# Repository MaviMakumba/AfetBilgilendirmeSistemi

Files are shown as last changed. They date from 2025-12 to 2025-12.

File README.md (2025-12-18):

# 🏢 IoT Tabanlı Akıllı Bina Yönetimi ve Otonom Afet Güvenlik Sistemi






> **Sakarya Üniversitesi - Nesnelerin İnterneti (IoT) Dersi Projesi**

Bu proje, geleneksel bina güvenliğini (NFC/RFID) akıllı afet yönetimiyle birleştiren hibrit bir IoT sistemidir. Sistem, **iki ayrı NodeMCU modülü** üzerinden çalışarak; giriş-çıkışları kontrol eder, deprem/yangın anında otonom karar vererek kilitleri açar ve tüm verileri **Firebase** tabanlı Web Dashboard ve Mobil Uygulama üzerinden sunar.

---

## 🚀 Projenin Amacı ve Özgün Değeri
Mevcut akıllı ev sistemleri genellikle sadece konfora odaklanır. Bu projenin temel farkı **hayat kurtarmaya** odaklanmasıdır.
* **Otonom Tahliye (M2M):** Deprem algılandığında Sensör Modülü, Kapı Modülü ile **MQTT** üzerinden haberleşerek kilitli kapıları otomatik açar.
* **Gelişmiş Deprem Algılama:** Basit titreşim sensörü yerine, sismolojide kullanılan **STA/LTA (Short Term Average / Long Term Average)** algoritması ile MPU6050 verileri işlenerek hatalı alarmlar önlenir.

---

## 🛠 Donanım Mimarisi
Sistem iki ana düğümden oluşur:

### 1. Kapı ve Erişim Kontrol Ünitesi (NodeMCU-1)
* **Görev:** Personel takibi ve kapı kilidi kontrolü.
* **Bileşenler:**
    * NodeMCU V3 (ESP8266)
    * RC522 NFC/RFID Okuyucu
    * SG90 Servo Motor (Kilit Mekanizması)
    * Buzzer & LED (Durum Bildirimi)

### 2. Çevresel İzleme ve Afet İstasyonu (NodeMCU-2)
* **Görev:** Binayı sürekli dinleyen "Duyu Organı".
* **Bileşenler:**
    * NodeMCU V3 (ESP8266)
    * **MPU6050:** 6 Eksenli İvme ve Jiroskop (Deprem Tespiti)
    * **MQ-2:** Yanıcı Gaz ve Duman Sensörü
    * **LM35:** Analog Sıcaklık Sensörü
    * Alarm Sistemi (Buzzer & RGB LED)
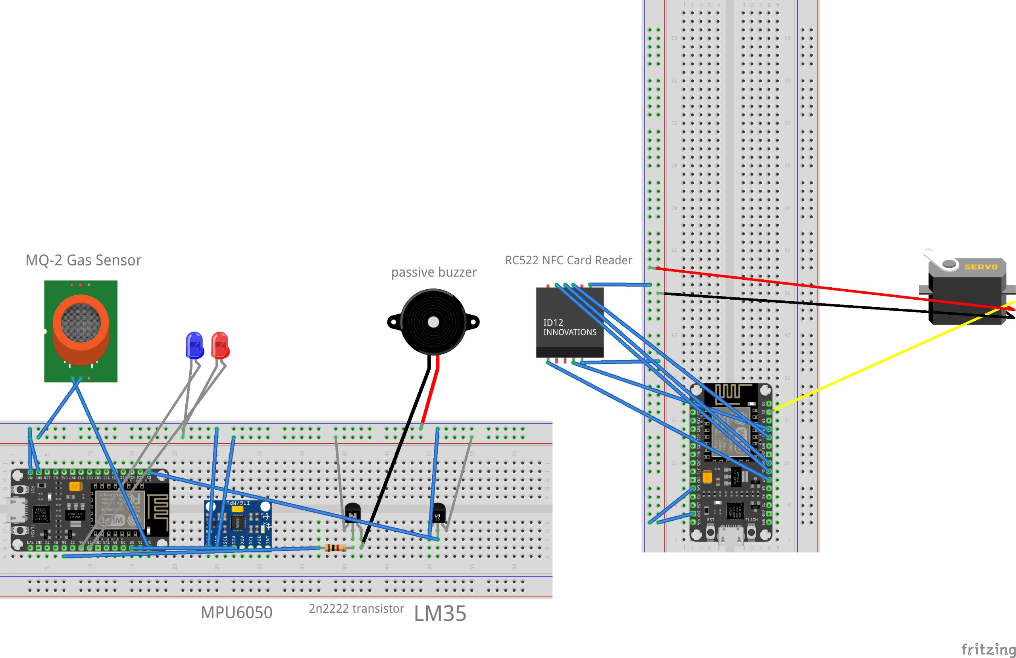
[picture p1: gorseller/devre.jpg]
Devre Resmi
    

---

## 💻 Yazılım ve Teknoloji Yığını

| Alan | Teknoloji / Platform | Kullanım Amacı |
| :--- | :--- | :--- |
| **Gömülü Yazılım** | Arduino IDE (C++) | ESP8266 kodlaması ve STA/LTA algoritması. |
| **Veritabanı** | Firebase Realtime DB | Kullanıcı verileri, loglar ve anlık durum senkronizasyonu. |
| **Haberleşme** | Adafruit IO (MQTT) | İki NodeMCU arasındaki M2M (Makineden Makineye) iletişim. |
| **Web Panel** | .NET MVC (C#) | Yönetici paneli, grafiksel raporlama ve geçmiş veri analizi. |
| **Mobil Panel** | Blynk IoT | Cepten anlık izleme ve "Push Notification" bildirimleri. |
| **Kart Yönetimi** | MIT App Inventor | NFC kartlara kişi tanımlamak için geliştirilen mobil araç. |

---

## 📊 Sistem Görselleri ve Arayüzler

### Web Dashboard (.NET MVC)
Sistemin genel durumunun, anlık gaz/sıcaklık verilerinin ve giriş-çıkış loglarının takip edildiği yönetim paneli.
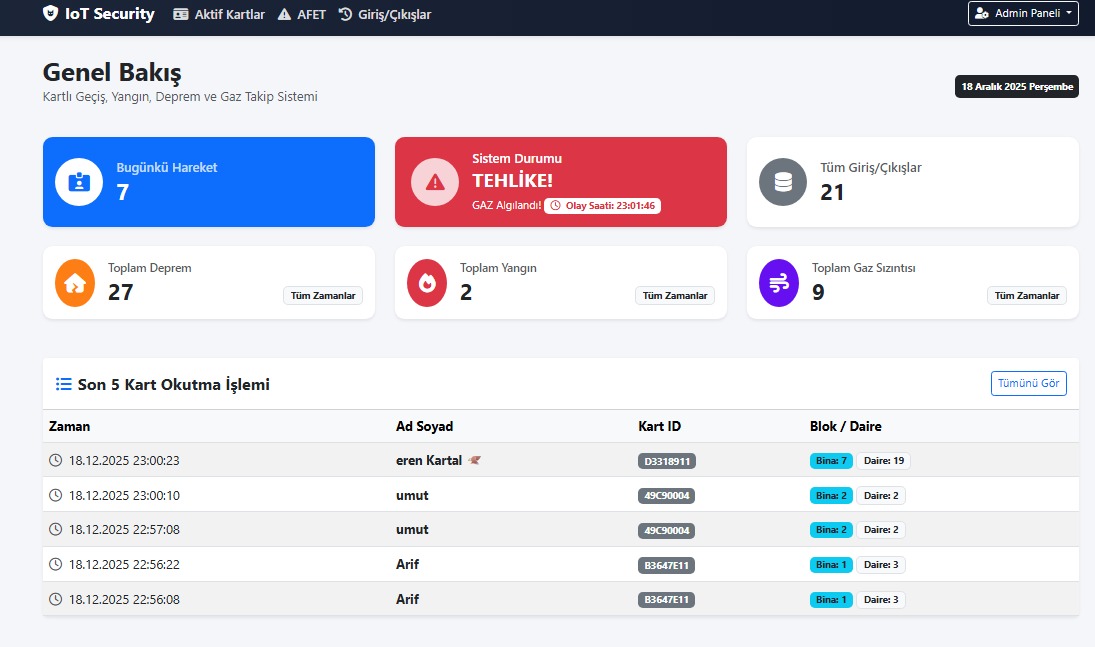
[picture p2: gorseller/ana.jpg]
AnaMenu

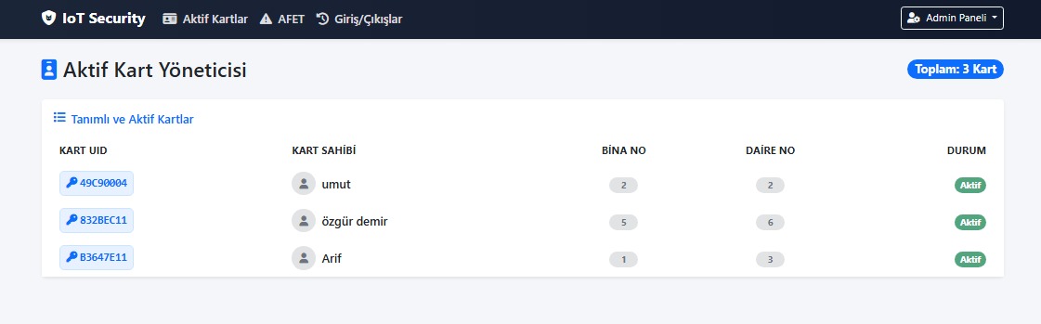
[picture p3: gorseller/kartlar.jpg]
Kartlar

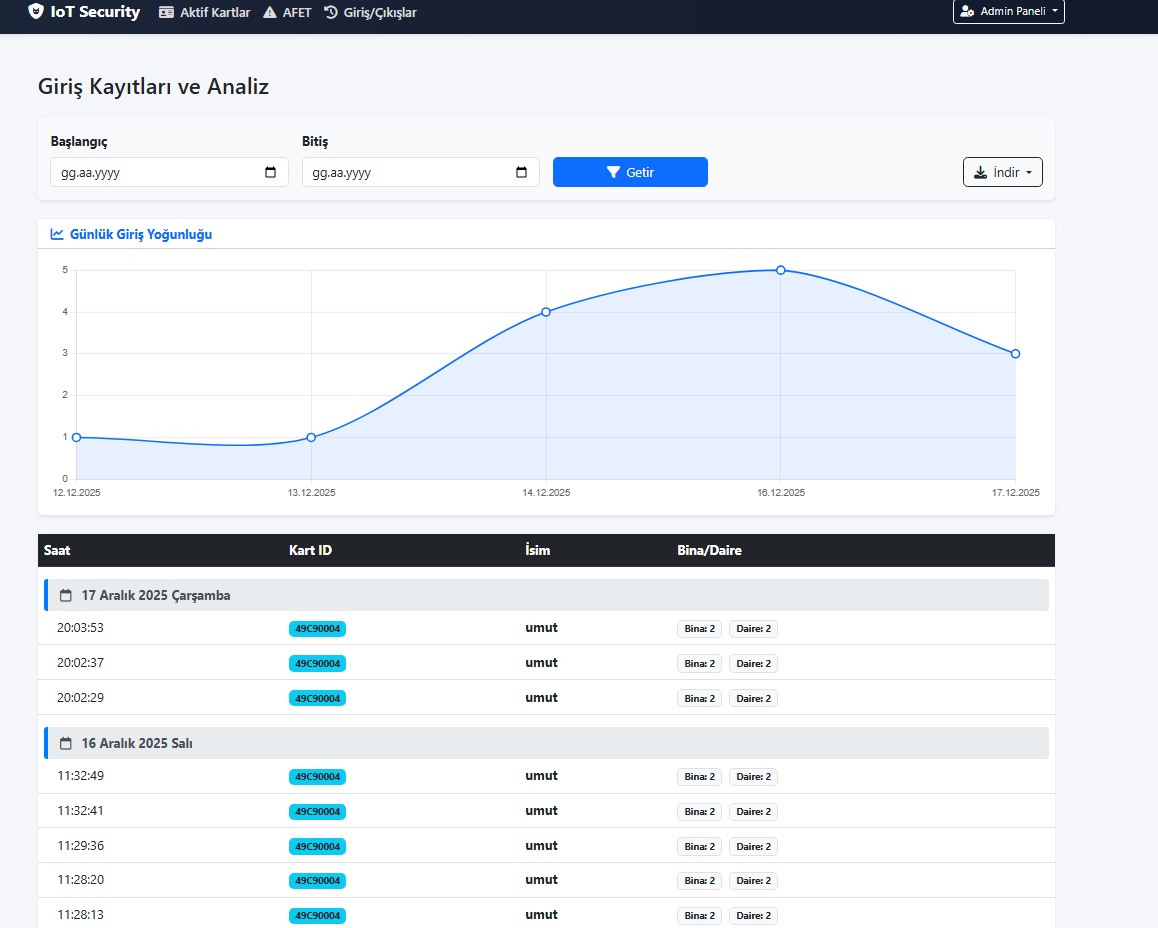
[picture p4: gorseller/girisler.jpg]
Girisler

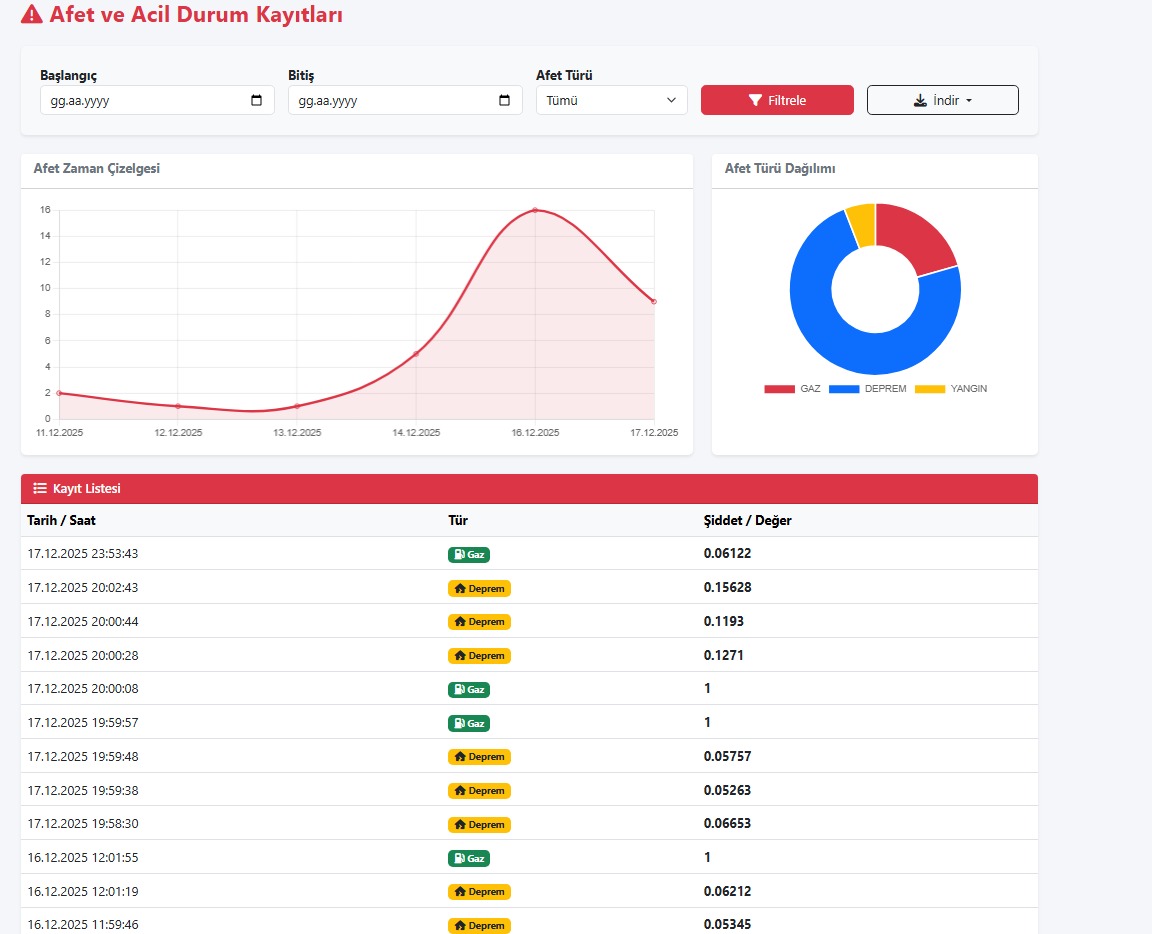
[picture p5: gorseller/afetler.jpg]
Afetler


### Mobil Uygulamalar
* **Blynk:** Ev sahibinin alarm durumunu gördüğü ekran.
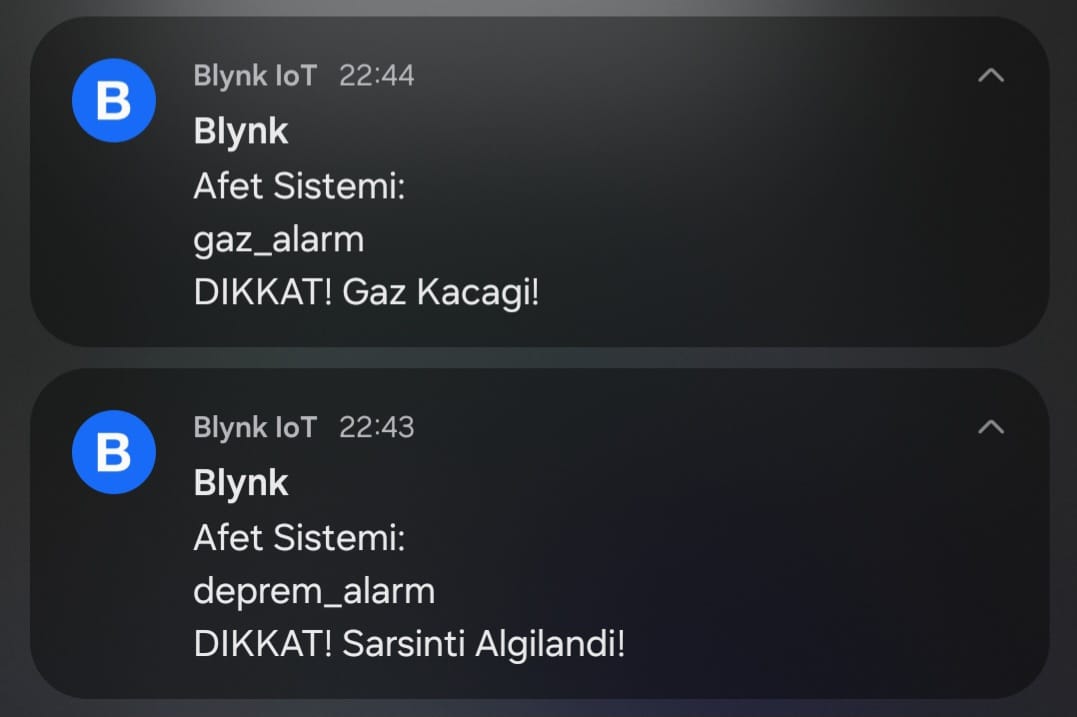
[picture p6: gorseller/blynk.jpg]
Blynk
 

* **Kart Yöneticisi:** Yöneticinin yeni kiracı/personel kartı tanımladığı arayüz.
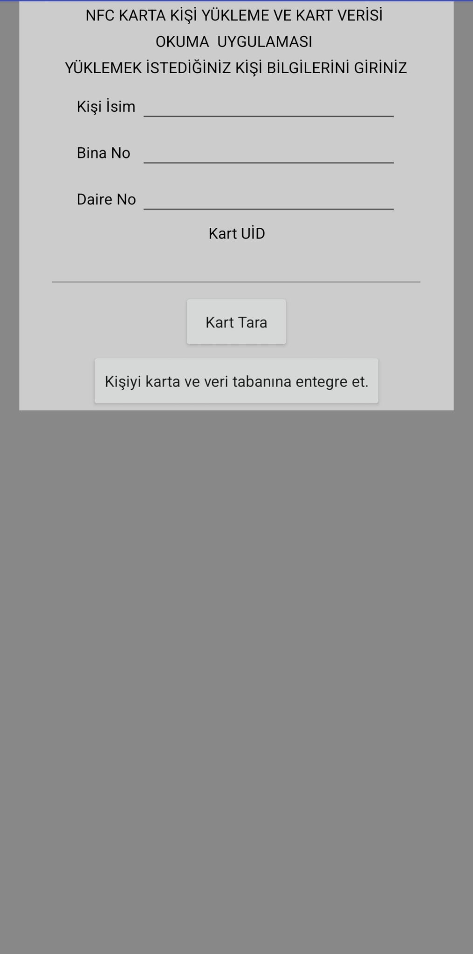
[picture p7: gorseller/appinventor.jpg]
AppInventor


---

## ⚙️ Kurulum ve Algoritma Detayları

### STA/LTA Deprem Algoritması
Sistem, sadece "sallantı var" demez; sarsıntının karakteristiğini analiz eder.
* **STA (Kısa Dönem):** Son 0.5 saniyedeki ivme ortalaması.
* **LTA (Uzun Dönem):** Son 30 saniyedeki zemin gürültüsü ortalaması.
* **Tetiklenme:** `Oran = STA / LTA`. Eğer Oran > 2.5 ise sistem **DEPREM** alarmı verir ve kapıları açar.

### Nasıl Çalıştırılır?
1.  `Arduino/` klasöründeki kodları NodeMCU kartlarına yükleyin.
2.  `WebPanel/` klasöründeki .NET projesini Visual Studio ile açıp Firebase bilgilerinizi girin.
3.  Blynk uygulamasından QR kodu taratarak mobil arayüzü klonlayın.

---

## 👥 Proje Ekibi
* **Eren Kartal** - B231210065
* **Umut Arda Vural** - B231210081
* **Özgür Demir** - B221210017

---
*Sakarya Üniversitesi, Bilgisayar ve Bilişim Bilimleri Fakültesi*

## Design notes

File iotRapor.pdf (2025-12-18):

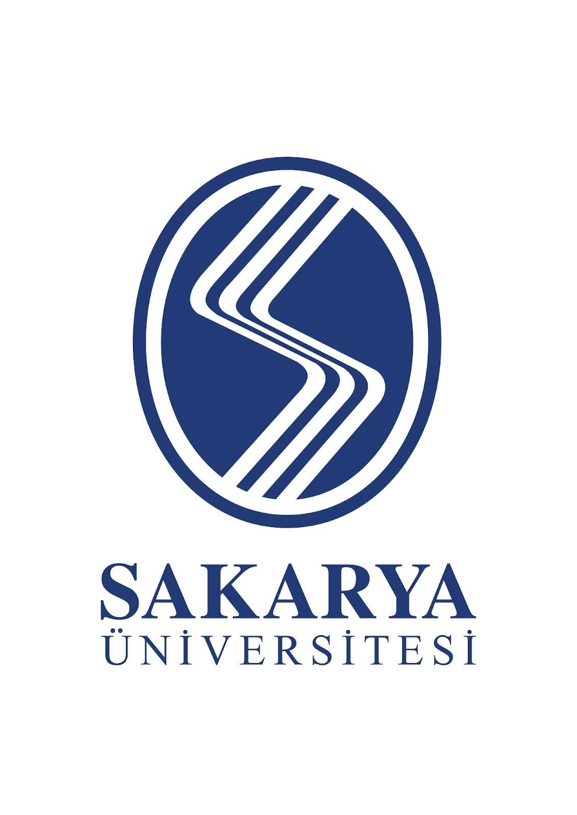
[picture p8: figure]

1) Proje Raporu
Proje Adı: IoT Tabanlı Akıllı Bina Yönetimi ve Otonom Afet Güvenlik Sistemi Ders: Nesnelerin İnterneti (IoT)
Platformlar: NodeMCU (ESP8266), Firebase Realtime Database, Adafruit MQTT, Blynk IoT Platformu
Hazırlayanlar:
Eren Kartal B231210065
Umut Arda Vural B231210081 Özgür Demir B221210017
Tarih: 19.12.2025
Özet
Bu proje, binalarda giriş-çıkış güvenliğini sağlayan ve aynı zamanda doğal afetlere (deprem, yangın) veya gaz sızıntılarına karşı otonom tepki verebilen entegre bir bina yönetim sistemidir. Sistem iki ana haberleşme düğümünden oluşur. Birinci düğüm; NFC teknolojisi ile personel/bina sakini takibi yapar, girişleri zaman damgalı olarak buluta (Firebase) kaydeder ve yetkisiz girişleri engeller. İkinci düğüm ise binanın "duyu organı" gibi çalışarak sarsıntı (MPU6050), sıcaklık (LM35) ve gaz (MQ-2) seviyelerini sürekli analiz eder.
Projenin en özgün yanı, M2M (Makineden Makineye) iletişim protokolü kullanmasıdır. Deprem algılandığı anda sensör düğümü, MQTT protokolü üzerinden kapı düğümüne sinyal göndererek kilitli kapıların otomatik açılmasını sağlar. Bu sayede panik anında tahliye süreci hızlandırılır ve can güvenliği maksimize edilir. Amaç ve Hedefler
Amaç: Geleneksel bina güvenliğini (kartlı geçiş), akıllı afet yönetimiyle birleştirerek; hem günlük kullanımda konfor sağlayan hem de acil durumlarda otonom kararlar alabilen hibrit bir IoT sistemi geliştirmek.
Hedefler:

### 1. Bulut Tabanlı Loglama: Binaya kimin, ne zaman girdiğinin anlık olarak

Firebase veritabanına işlenmesi.

### 2. Yönetici Kolaylığı: Kod güncellemesine gerek kalmadan, "Master Kart"

kullanılarak yeni kullanıcıların sisteme fiziksel olarak eklenebilmesi.

### 3. Gelişmiş Deprem Algılama: Basit titreşim sensörleri yerine 6 eksenli

ivmeölçer (MPU6050) ve STA/LTA (Kısa Dönem/Uzun Dönem Ortalaması) algoritması kullanarak hatalı alarmları önleyen sismik algılama.

### 4. Acil Durum Senaryosu (M2M): Deprem veya yangın anında insan

müdahalesine gerek kalmadan kapı kilitlerinin (Servo) otomatik açılması.

### 5. Mobil İzleme: Bina yöneticisinin Blynk uygulaması üzerinden sıcaklık, gaz ve

sarsıntı durumunu canlı izleyebilmesi ve anlık "Push Notification" alabilmesi.
Sistem Gereksinimleri
Donanım Bileşenleri
- Mikrodenetleyici: 2 x NodeMCU V3 (ESP8266 Wi-Fi Modülü).
- Biri Kapı Kontrol Ünitesi, diğeri Sensör İstasyonu olarak.
- Kimlik Doğrulama: 1 x MFRC522 RFID/NFC Okuyucu Kit (13.56 MHz).
- Mekanik Kontrol: 1 x SG90 Servo Motor (Kapı kilidi simülasyonu için).
- Sensörler:
- 1 x MPU6050 (3 Eksen İvme ve 3 Eksen Jiroskop) - Deprem için.
- 1 x MQ-2 (Yanıcı Gaz ve Duman Sensörü).
- 1 x LM35 (Analog Sıcaklık Sensörü).
- Uyarıcılar: 1 x Pasif Buzzer, 2 x Led Modülü. Devre Tasarımı

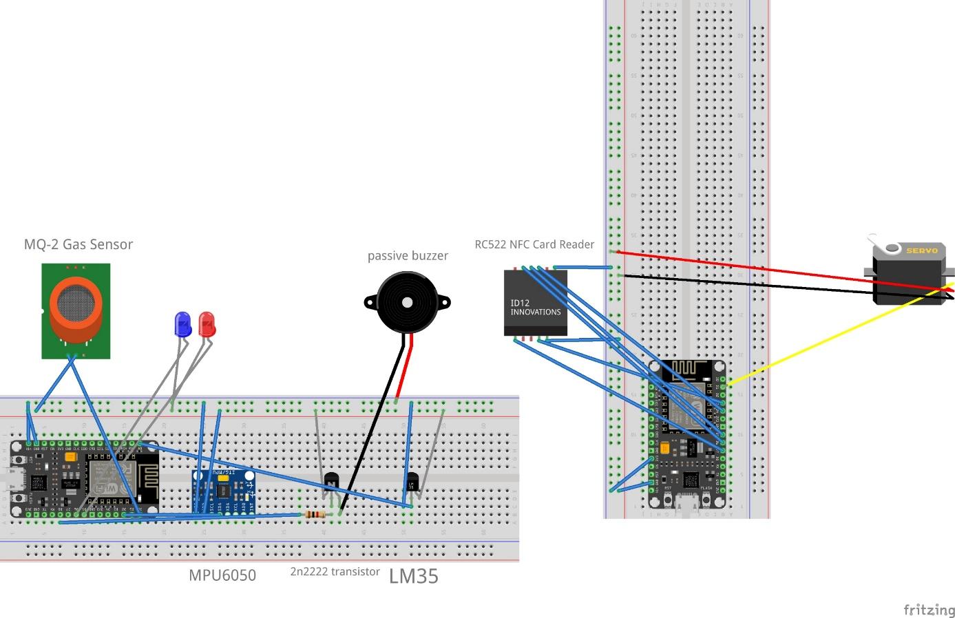
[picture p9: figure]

Yazılım ve Bulut Teknolojileri
- Geliştirme Ortamı: Arduino IDE (C++).
- Veritabanı: Google Firebase Realtime Database (JSON formatında veri saklama).
- Haberleşme Protokolü: Adafruit IO (MQTT Broker) – Cihazlar arası iletişim için.
- Kullanıcı Arayüzü: Blynk IoT (Mobil Dashboard).
- Zaman Sunucusu: NTP (Network Time Protocol) – Loglara doğru tarih/saat basmak için.
Mimari Tasarım
Sistem, birbirinden bağımsız çalışan ancak MQTT üzerinden haberleşen iki ana modülden oluşur:

### 1. Modül: Akıllı Kapı ve Erişim Kontrol Ünitesi

- Firebase ile sürekli senkronize çalışır.
- Okunan kartın ID'sini veritabanından sorgular.
- Yetkili ise servo motoru 90 derece açar, 5 saniye bekler ve kapatır.

- Kritik Görev: Arka planda sürekli MQTT kanalını dinler. Eğer "Acil Durum" mesajı gelirse kart sormadan kapıyı açar.

### 2. Modül: Çevresel İzleme ve Afet Tespit Ünitesi

- Sensör verilerini sürekli işler (Loop döngüsü içinde).
- Deprem için matematiksel STA/LTA algoritması koşturur.
- Tehlike (Gaz/Yangın/Deprem) tespit ettiğinde:
1. Sesli ve Işıklı (Kırmızı LED) alarm verir.
2. Blynk uygulamasına bildirim atar.
3. Firebase "Afet_Gecmisi" tablosuna olayı kaydeder.
4. MQTT üzerinden kapı modülüne "AÇ" komutu yollar. UML Tasarımları
(Bu bölümdeki diyagramları raporuna görsel olarak eklemelisin. Aşağıdaki metinler diyagramların mantığını anlatır.)
1) Use Case Diyagramı
- Aktörler: Bina Sakini, Yönetici, Sistem (Otonom).
- Senaryolar:
- Kartlı Giriş: Bina sakini kart okutur -> Sistem kapıyı açar.
- Kart Ekleme: Yönetici Master kartı okutur -> Sistem "Kayıt Modu"na geçer.
- Afet Yönetimi: Sistem depremi algılar -> Kapıları açar -> Yöneticinin telefonuna bildirim gönderir.

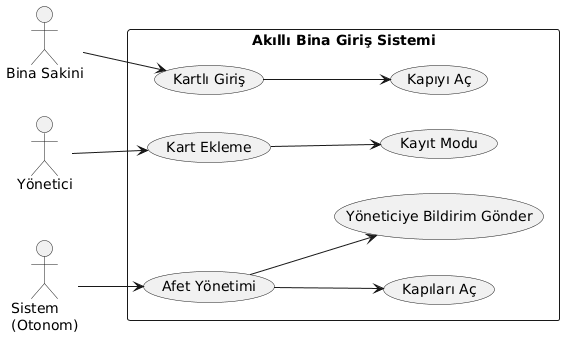
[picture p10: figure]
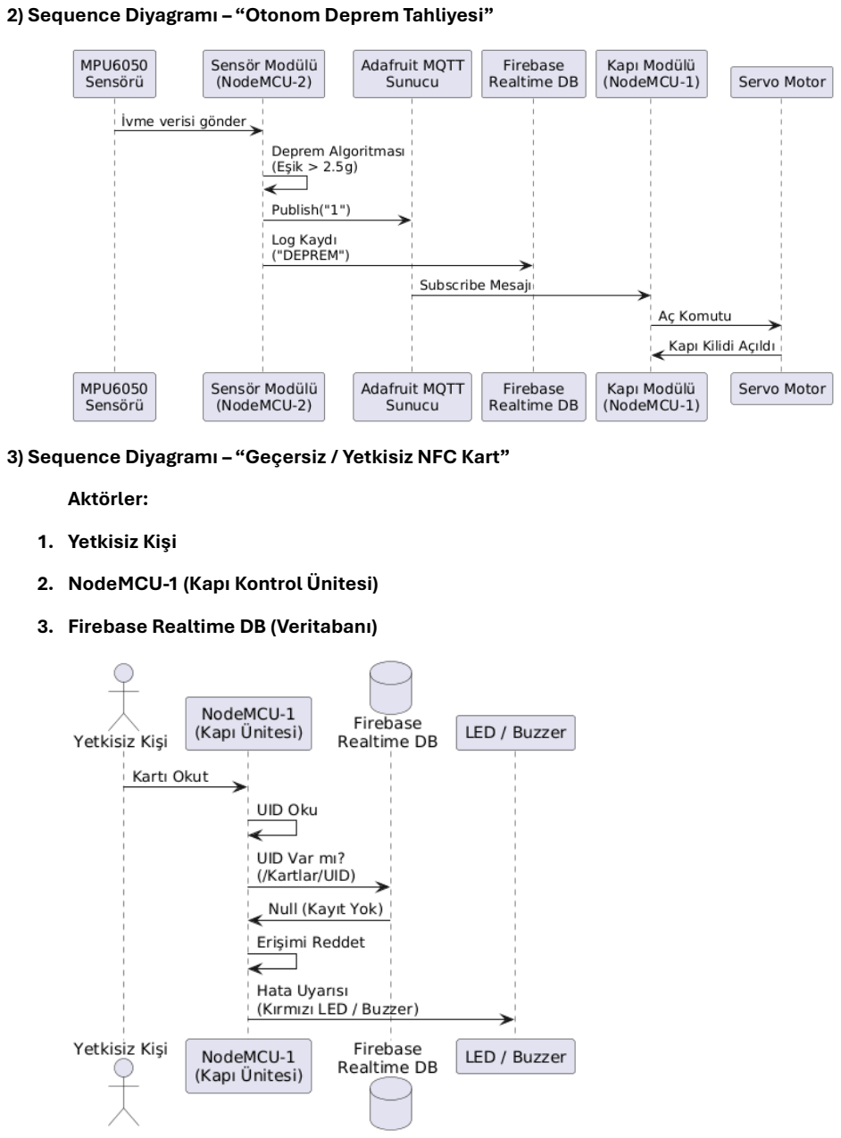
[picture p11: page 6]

2) Sequence Diyagramı – “Otonom Deprem Tahliyesi”
3) Sequence Diyagramı – “Geçersiz / Yetkisiz NFC Kart” Aktörler:

### 1. Yetkisiz Kişi

### 2. NodeMCU-1 (Kapı Kontrol Ünitesi)

### 3. Firebase Realtime DB (Veritabanı)

4) Component (Bileşen) Diyagramı
A) NodeMCU-1 (Kapı ve Giriş Ünitesi) Bu kutunun içine şu modülleri yaz:
- NFC Reader Service: Kart okuma işlemi.
- Firebase Auth Client: Veritabanı yetki sorgulama.
- Lock Controller: Servo motoru yöneten kısım.
- MQTT Subscriber: Deprem sinyalini dinleyen modül.
B) NodeMCU-2 (Sensör ve Afet Ünitesi) Bu kutunun içine şu modülleri yaz:
- Sensor Manager: MPU6050, MQ-2 ve LM35 verilerini okuyan kısım.
- Earthquake Algo (STA/LTA): Deprem hesaplaması yapan algoritma.
- Alarm Controller: Buzzer ve RGB LED yönetimi.
- Blynk Client: Mobil uygulamaya veri gönderme.
- MQTT Publisher: Deprem anında kapıya "Aç" sinyali gönderen modül.
- Firebase Logger: Afet verilerini kaydeden kısım.
C) Cloud Services (Bulut Katmanı) Bu kutunun içine şu servisleri yaz:
- Firebase Realtime DB: Kullanıcı listesi ve Loglar.
- Adafruit IO (MQTT Broker): İki cihazın konuşma hattı.
- Blynk Server: Mobil uygulama sunucusu.

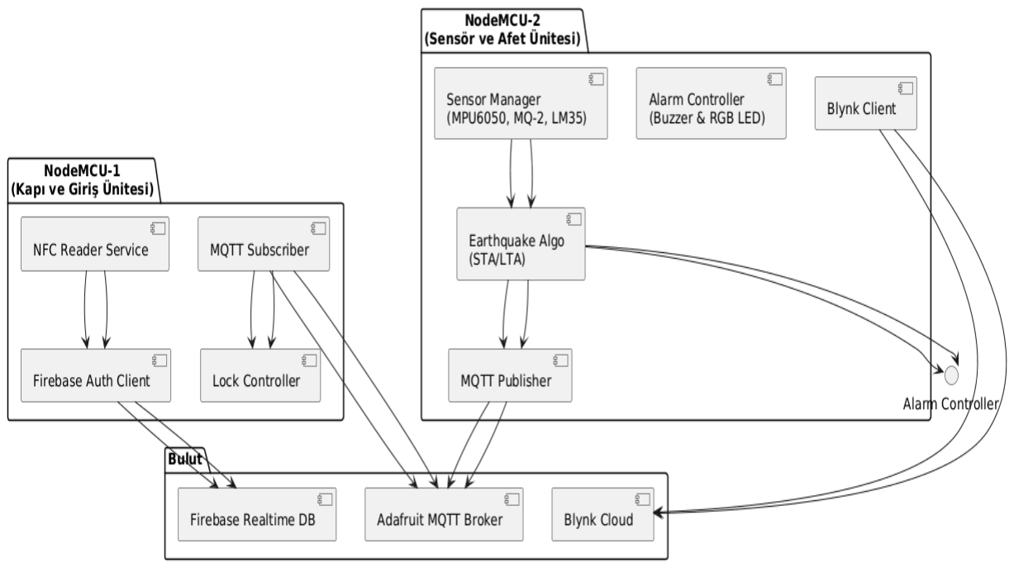
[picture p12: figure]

Elektronik Devre Tasarımı (Pin Bağlantıları)
A) Kapı Kontrol Ünitesi (NodeMCU-1)
- MFRC522 (NFC):
- SDA (SS) -> D4
- SCK -> D5
- MOSI -> D7
- MISO -> D6
- RST -> D3
- Servo Motor: Sinyal Pini -> D1 (PWM).
B) Sensör ve Afet Ünitesi (NodeMCU-2)
- MPU6050 (Deprem): SDA -> D2, SCL -> D1 (I2C Hattı).
- MQ-2 (Gaz): Analog/Dijital Çıkış -> D0.
- LM35 (Sıcaklık): Sinyal -> A0.
- Buzzer: Pozitif -> D8.
- RGB LED: Kırmızı -> D5, Yeşil -> D6, Mavi -> D7. Gerçekleme Süreci ve Yazılım Mantığı
Projenin yazılımında üç kritik algoritma kullanılmıştır:

### 1. Dinamik Kart Yönetimi: Kod içinde MASTER_KART_ID olarak belirlenen kart

okutulduğunda, cihaz bir durum makinesi (State Machine) gibi davranarak "Kayıt Modu"na geçer. Bu modda okutulan herhangi bir yabancı kart, otomatik olarak Firebase JSON ağacına yeni kullanıcı olarak eklenir.

### 2. STA/LTA Deprem Algoritması: Deprem tespiti için sadece "titreşim var mı?"

kontrolü yapılmamıştır. Sismolojide kullanılan, kısa süreli ortalamanın (STA) uzun süreli ortalamaya (LTA) oranlanması yöntemi kullanılmıştır.
- Formül: Oran = STA / LTA
- Eğer oran 2.5 değerini aşarsa ve ivme belirli bir büyüklükteyse, sistem bunu "anlık çarpma" değil "sismik hareket" olarak yorumlar.

### 3. JSON Veri Paketleme: Firebase'e veri gönderilirken ham string yerine

FirebaseJson kütüphanesi kullanılmıştır. Bu sayede veriler { "isim": "Ahmet", "tarih": "18.12.2025", "kart_id": "XXYY" } formatında yapısal olarak saklanır.

Test Planı ve Sonuçlar
- Test 1: Normal Giriş: Tanımlı NFC kart okutuldu.
- Beklenen: Servo motor 90° döndü, Firebase "Giris_Kayitlari"na log düştü.
- Sonuç: Başarılı. Yeşil LED yandı.
- Test 2: Yetkisiz Giriş: Tanımsız kart okutuldu.
- Beklenen: Kapı açılmadı, Servo tepki vermedi.
- Sonuç: Başarılı. Seri port ekranında "Erişim Reddedildi" uyarısı görüldü.
- Test 3: Deprem Simülasyonu: Sensör modülü el ile sertçe sarsıldı.
- Beklenen: Buzzer çaldı, Blynk bildirimi geldi, Kapı modülündeki servo otomatik açıldı.
- Sonuç: MQTT gecikmesi <1 saniye olarak ölçüldü. Kapı başarıyla açıldı.
- Test 4: Gaz Kaçağı: Sensöre çakmak gazı yaklaştırıldı.
- Beklenen: Blynk uygulamasında "Gaz Kaçağı" uyarısı görüldü.
- Sonuç: Başarılı. Kırmızı alarm LED'i yandı.
Maliyet Analizi
Bileşen Adı | Adet | Birim Fiyat (Tahmini) | Toplam
NodeMCU V3 (ESP8266) | 2 | 150 TL | 300 TL
MFRC522 NFC Kiti | 1 | 90 TL | 90 TL
MPU6050 İvme Sensörü | 1 | 150 TL | 150 TL
MQ-2 Gaz Sensörü | 1 | 70 TL | 70 TL
SG90 Servo Motor | 1 | 75 TL | 75 TL
LM35 Sıcaklık Sensörü | 1 | 20 TL | 20 TL
Jumper & Breadboard | 1 | 100 TL | 100 TL
GENEL TOPLAM | | | 805 TL

2) İş Fikri ve Business Model Canvas
İş Fikri: " IoT Tabanlı Akıllı Bina Yönetimi ve Otonom Afet Güvenlik Sistemi" Problem: Mevcut akıllı bina sistemleri konfora odaklıdır ancak afet anında işgörmez kilitlere dönüşmektedir. Deprem anında kapıların sıkışması veya kilitli kalması, tahliyeyi imkansız hale getirebilir. Ayrıca gaz kaçakları, deprem sonrası ikincil felaketlere yol açmaktadır.
Çözüm: Giriş güvenliğini sağlarken aynı zamanda binayı sürekli dinleyen, deprem anında kapıları otomatik açarak "kaçış yolu yaratan" entegre bir sistem. Business Model Canvas Özeti:

### 1. Değer Önerisi: "Sadece kapınızı açmaz, hayatınızı kurtarır." Deprem anında

otonom tahliye garantisi.

### 2. Müşteri Segmentleri: Deprem riski yüksek bölgelerdeki (İstanbul vb.) site

yönetimleri, kentsel dönüşüm projeleri, akıllı ev sahipleri.

### 3. Gelir Akışları: Donanım satışı + Bulut loglama hizmeti için yıllık abonelik

(SaaS).

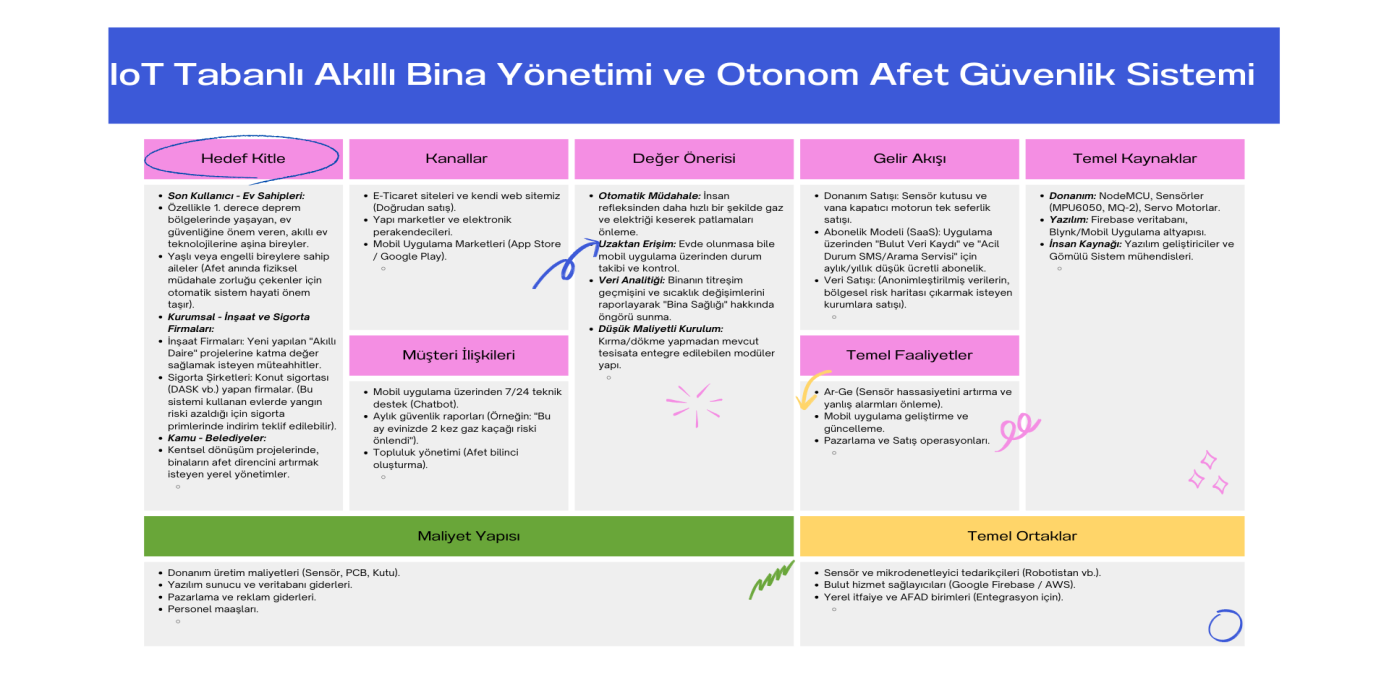
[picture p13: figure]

3) Büyük Veri (Big Data) Potansiyeli
Eğer bu sistem binlerce binada (örneğin tüm İstanbul'da) aktif olsaydı, elde edilecek veri muazzam bir değer taşırdı:

### 1. Kitle Kaynaklı Sismograf Ağı (Crowdsourced Seismology):

Her binadaki MPU6050 sensörü, depremin yayıldığı saniyelerde bir veri noktası oluşturur. Binlerce cihazdan gelen bu veriler;

- Depremin merkez üssünü saniyeler içinde doğrulayabilir.
- Hangi mahallelerin daha şiddetli sarsıldığını gösteren "Anlık Hasar Tahmin Haritası" çıkarabilir.

### 2. Gaz ve Yangın Risk Haritası:

Binalardan gelen MQ-2 verileri analiz edilerek, şehirdeki gaz kaçağı riskinin yüksek olduğu, altyapının eski olduğu bölgeler tespit edilebilir.
Gerekli Altyapı:
- Bu kadar büyük veriyi işlemek için Firebase yerine Apache Kafka (Stream Processing) ve MongoDB (Big Data Storage) gibi teknolojilere geçiş yapılmalıdır.
- Anlık analiz için yapay zeka destekli Anomaly Detection (Anomali Tespiti) algoritmaları kullanılmalıdır.
Uygulama Resimleri

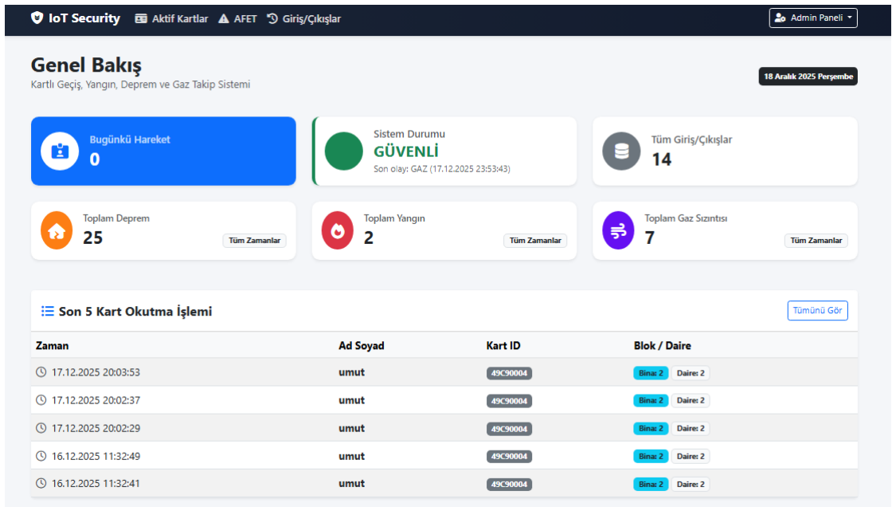
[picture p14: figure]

Şekil 1: .NET MVC mimarisi ile geliştirilen ve verileri Firebase üzerinden anlık olarak çeken "IoT Security" projesinin Genel Bakış (Dashboard) ekranı. Bu panelde sistemin güvenlik durumu, toplam afet istatistikleri ve son kartlı geçiş hareketleri özetlenmektedir.

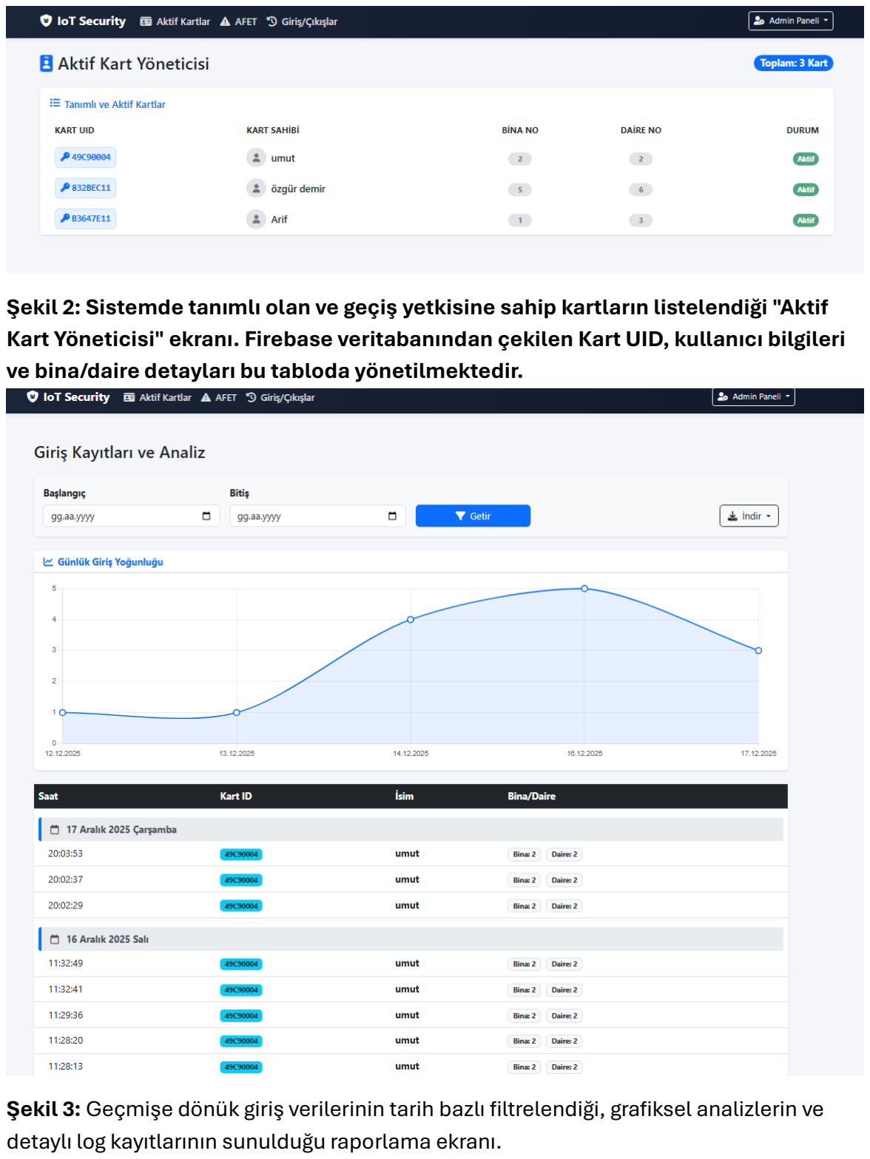
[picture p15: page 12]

Şekil 2: Sistemde tanımlı olan ve geçiş yetkisine sahip kartların listelendiği "Aktif Kart Yöneticisi" ekranı. Firebase veritabanından çekilen Kart UID, kullanıcı bilgileri ve bina/daire detayları bu tabloda yönetilmektedir.

Şekil 3: Geçmişe dönük giriş verilerinin tarih bazlı filtrelendiği, grafiksel analizlerin ve detaylı log kayıtlarının sunulduğu raporlama ekranı.

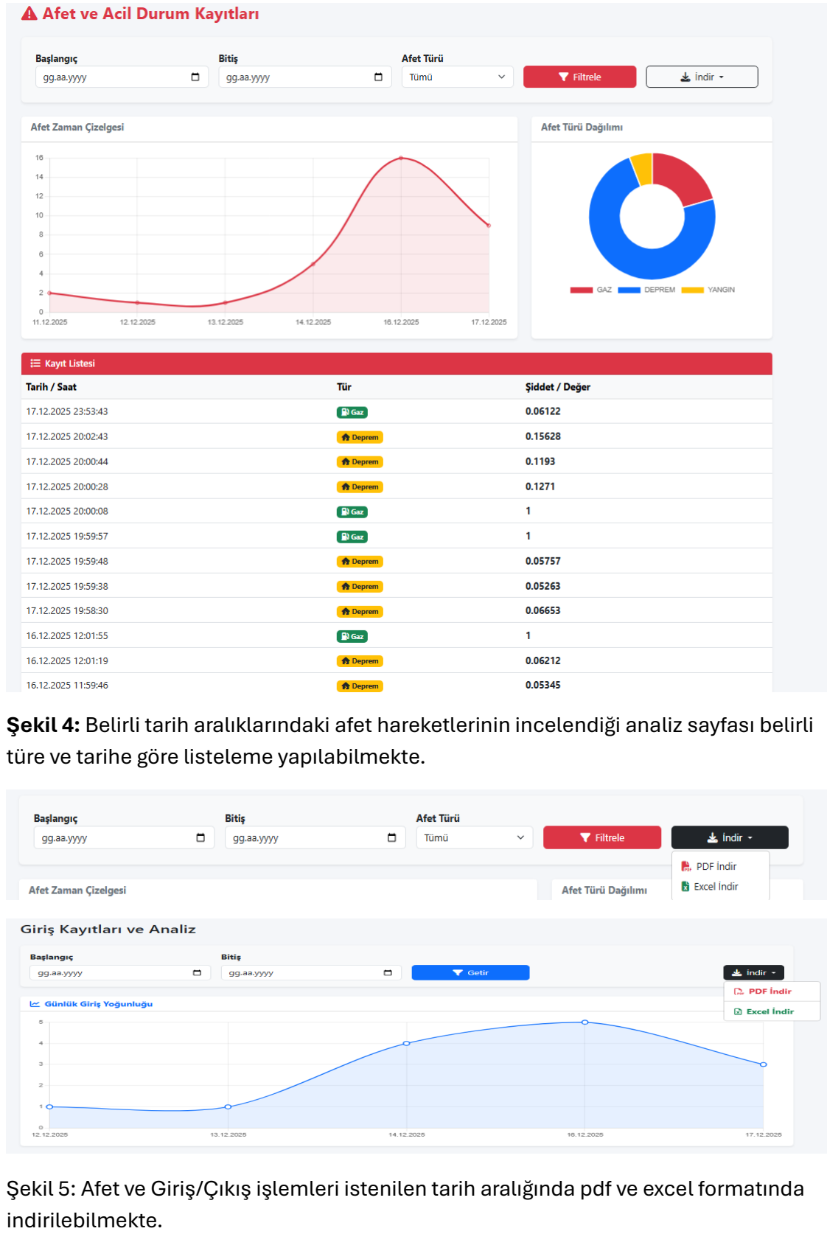
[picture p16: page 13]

Şekil 4: Belirli tarih aralıklarındaki afet hareketlerinin incelendiği analiz sayfası belirli türe ve tarihe göre listeleme yapılabilmekte.

Şekil 5: Afet ve Giriş/Çıkış işlemleri istenilen tarih aralığında pdf ve excel formatında indirilebilmekte.

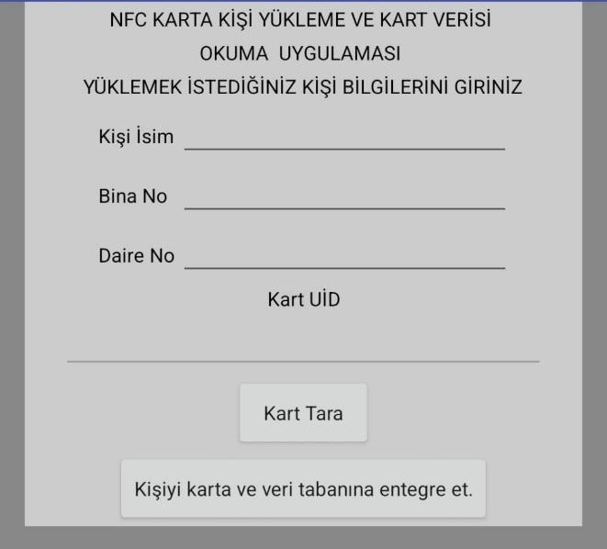
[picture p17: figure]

Şekil 6: Donanım tarafında "Admin Kart" protokolü ile kilidi açılan kartların tanımlandığı mobil arayüz. "Kart Tara" butonu ile sisteme son okutulan hedef kartın UID'si çekilir; girilen kullanıcı bilgileri hem Firebase veritabanına işlenir.( App Inventor)

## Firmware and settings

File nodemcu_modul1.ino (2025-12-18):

#define BLYNK_TEMPLATE_ID "TMPL6_E93vIuf"
#define BLYNK_TEMPLATE_NAME "Afet Sistemi"
#define BLYNK_AUTH_TOKEN "uVb_FSvif9LfXYwK0c1Onp_nOEmY2oFg"

#define BLYNK_PRINT Serial
#include <ESP8266WiFi.h>
#include <BlynkSimpleEsp8266.h>
#include <Wire.h>
#include <MPU6050_light.h>
#include "Adafruit_MQTT.h"
#include "Adafruit_MQTT_Client.h"
#include <time.h>
#include <Firebase_ESP_Client.h>

// --- WIFI AYARLARI ---
char ssid[] = "";
char pass[] = "";

// --- ADAFRUIT MQTT AYARLARI ---
#define AIO_SERVER      ""
#define AIO_SERVERPORT  
#define AIO_USERNAME    ""
#define AIO_KEY         ""

WiFiClient client;
Adafruit_MQTT_Client mqtt(&client, AIO_SERVER, AIO_SERVERPORT, AIO_USERNAME, AIO_KEY);
Adafruit_MQTT_Publish kapiYayin = Adafruit_MQTT_Publish(&mqtt, AIO_USERNAME "/feeds/kapi-kontrol");

// --- PINLER ---
#define PIN_MQ2 D0
#define PIN_LM35 A0
#define PIN_BUZZER D8
#define PIN_RED D5
#define PIN_GREEN D6
#define PIN_BLUE D7

// --- FIREBASE AYARLARI ---
#define API_KEY ".."
#define DATABASE_URL "---.."

FirebaseData fbdo;
FirebaseAuth auth;
FirebaseConfig config;

MPU6050 mpu(Wire); // MPU Nesnesi
BlynkTimer timer;

// --- DEPREM ALGORİTMASI ---
float st_algo_STA = 0.0;
float st_algo_LTA = 0.001; 
float STA_alpha = 0.20; 
float LTA_alpha = 0.02;
const float RATIO_THRESHOLD = 2.5;

bool alarmDurumu = false;
unsigned long sonAlarmZamani = 0;
const float YANGIN_SINIRI = 50.0; 

void MQTT_connect();

void setup() {
  Serial.begin(115200);
  
  pinMode(PIN_MQ2, INPUT);
  pinMode(PIN_BUZZER, OUTPUT);
  pinMode(PIN_RED, OUTPUT);
  pinMode(PIN_GREEN, OUTPUT);
  pinMode(PIN_BLUE, OUTPUT);
  
  renkAyarla(0,1,0); // Yeşil

  // I2C Başlatma
  Wire.begin(D2, D1); // SDA=D2, SCL=D1

  // MPU6050 Başlatma
  byte status = mpu.begin();
  Serial.print("MPU Durumu: "); Serial.println(status);
  
  if (status != 0) {
    Serial.println("MPU hatasi! Baglantilari kontrol et.");
    while (1) { delay(10); } // Hata varsa dur
  }

  Serial.println("MPU6050 Baglandi! Kalibrasyon yapiliyor, kipirdatma...");
  delay(1000);
  mpu.calcOffsets(); // Sensörü sıfırlar
  Serial.println("Kalibrasyon Tamam!");

  // Blynk Başlat
  Blynk.begin(BLYNK_AUTH_TOKEN, ssid, pass);

  config.database_url = DATABASE_URL;
  config.signer.tokens.legacy_token = API_KEY;
  
  Firebase.begin(&config, &auth);
  Firebase.reconnectWiFi(true);
  
  timer.setInterval(50L, sensorDongusu);

  Serial.print("Saat sunucusuna baglaniyor...");
  // Türkiye Saati (UTC+3) -> 3 * 3600 saniye
  configTime(3 * 3600, 0, "pool.ntp.org", "time.nist.gov"); 

  // Saatin güncellenmesini bekle
  while (time(nullptr) < 1000) {
    delay(100); Serial.print(".");
  }
  Serial.println("\nSaat Guncellendi!"); 
}

void loop() {
  Blynk.run();
  timer.run();
  MQTT_connect();
}

// --- ZAMAN ALMA FONKSİYONU ---
String zamanDamgasiAl() {
  time_t now = time(nullptr);
  struct tm* p_tm = localtime(&now);
  
  char buffer[30];
  // Format: Gün.Ay.Yıl Saat:Dakika:Saniye
  sprintf(buffer, "%02d.%02d.%d %02d:%02d:%02d", 
          p_tm->tm_mday, p_tm->tm_mon + 1, p_tm->tm_year + 1900, 
          p_tm->tm_hour, p_tm->tm_min, p_tm->tm_sec);
          
  return String(buffer);
}

void sensorDongusu() {
  // 1. MPU6050 GÜNCELLEME VE OKUMA
  mpu.update();

  // G cinsinden ivme değerleri (1.0 = Yerçekimi)
  float accX = mpu.getAccX();
  float accY = mpu.getAccY();
  float accZ = mpu.getAccZ() - 1.0; // Yerçekimini çıkar (9.81 değil 1.0)
  
  // Titreşim Büyüklüğü
  float anlikIvme = sqrt(accX*accX + accY*accY + accZ*accZ);

  // STA/LTA Hesaplama
  st_algo_STA = (st_algo_STA * (1.0 - STA_alpha)) + (anlikIvme * STA_alpha);
  st_algo_LTA = (st_algo_LTA * (1.0 - LTA_alpha)) + (anlikIvme * LTA_alpha);
  
  float oran = 0.0;
  if (st_algo_LTA > 0) oran = st_algo_STA / st_algo_LTA;

  // 2. GAZ OKUMA
  int gazDurumu = digitalRead(PIN_MQ2); 
  bool gazTehlikesi = (gazDurumu == LOW);

  // 3. SICAKLIK OKUMA
  float toplamOkuma = 0;
  
  // 1. Dalgalanmayı önlemek için 10 kez oku ve topla
  for (int i = 0; i < 10; i++) {
    toplamOkuma += analogRead(PIN_LM35);
    delay(5); 
  }
  
  // 2. Ortalamayı al
  float ortalamaHamDeger = toplamOkuma / 10.0;

  // 3. Hesaplama (Düşük voltaj sorununu çözmek için SONUNA * 10 EKLENDİ)
  // Normal formül: (HamDeger * 3300) / 10240
  float sicaklik = ((ortalamaHamDeger * 3300.0) / 10240.0) * 10.0;

  // 4. İnce Ayar
  bool yanginTehlikesi = (sicaklik > YANGIN_SINIRI);

  // --- ALARM KONTROLÜ ---
  if (!alarmDurumu) {
    // Eşik değer kontrolü
    if (oran > RATIO_THRESHOLD && st_algo_STA > 0.05) { 
      alarmBaslat("DEPREM");
    } 
    else if (gazTehlikesi) {
      alarmBaslat("GAZ");
    }
    else if (yanginTehlikesi) {
      alarmBaslat("YANGIN");
    }
  } 
  else 
  {
    if (millis() - sonAlarmZamani > 5000) 
    {
       if (oran < RATIO_THRESHOLD && !gazTehlikesi && !yanginTehlikesi)
       {
         alarmDurdur();
       }
    }
  }

  // --- BLYNK VERİ GÖNDERME ---
  static unsigned long sonGonderim = 0;
  if (millis() - sonGonderim > 1000) {
    Blynk.virtualWrite(V0, sicaklik); 
    Blynk.virtualWrite(V2, oran);    
    sonGonderim = millis();
  }
}

void alarmBaslat(String tur) {
  if (millis() - sonAlarmZamani < 2000) return; 
  
  alarmDurumu = true;
  sonAlarmZamani = millis();
  
  Serial.println("ALARM: " + tur);
  renkAyarla(1, 0, 0); // Kırmızı
  
  if (tur == "DEPREM") tone(PIN_BUZZER, 1000);
  else if (tur == "GAZ") tone(PIN_BUZZER, 500);
  else if (tur == "YANGIN") tone(PIN_BUZZER, 1500);

  if (tur == "DEPREM") Blynk.logEvent("deprem_alarm", "DIKKAT! Sarsinti Algilandi!");
  else if (tur == "GAZ") Blynk.logEvent("gaz_alarm", "DIKKAT! Gaz Kacagi!");
  else if (tur == "YANGIN") Blynk.logEvent("yangin_alarm", "DIKKAT! Yuksek Sicaklik/Yangin!");

  // İşlemciye nefes aldır
  yield();

  // --- LOGLAMA KISMI ---
  String tarihSaat = zamanDamgasiAl();
  float deger = 0.0;
  
  if (tur == "DEPREM") deger = st_algo_STA; // Deprem büyüklüğü (STA)
  else if (tur == "GAZ") deger = 1.0;       // Gaz var (1)
  else if (tur == "YANGIN") deger = (analogRead(PIN_LM35) * 330.0) / 1024.0; // Sıcaklık
  
  FirebaseJson json;
  json.set("tur", tur);
  json.set("deger", deger);
  json.set("tarih", tarihSaat);

  // İşlemciye nefes aldır
  yield();
  
  // "/Afet_Gecmisi" altına yeni kayıt ekle
  Firebase.RTDB.pushJSON(&fbdo, "/Afet_Gecmisi", &json);
  // ----------------------------


  kapiYayin.publish(1);
}

void alarmDurdur() {
  alarmDurumu = false;
  renkAyarla(0, 1, 0); 
  noTone(PIN_BUZZER);
  digitalWrite(PIN_BUZZER, LOW);
}

void renkAyarla(int r, int g, int b) {
  digitalWrite(PIN_RED, r); digitalWrite(PIN_GREEN, g); digitalWrite(PIN_BLUE, b);
}

void MQTT_connect() {
  int8_t ret;
  if (mqtt.connected()) return;
  uint8_t retries = 3;
  while ((ret = mqtt.connect()) != 0) { 
       mqtt.disconnect();
       delay(2000);  
       retries--;
       if (retries == 0) break;
  }
}
